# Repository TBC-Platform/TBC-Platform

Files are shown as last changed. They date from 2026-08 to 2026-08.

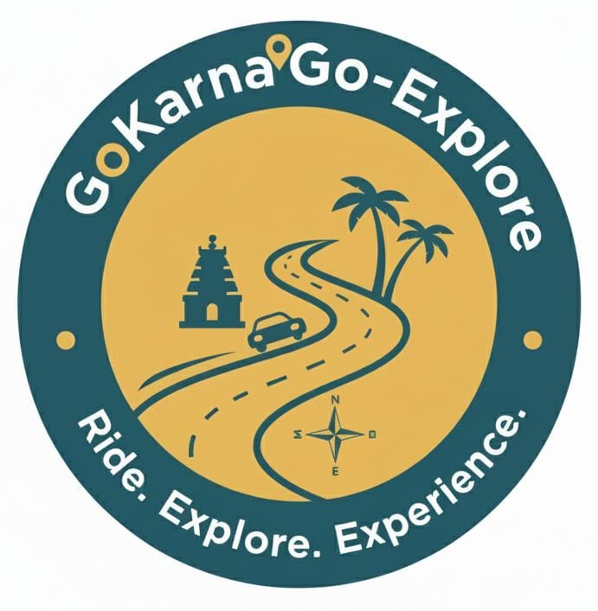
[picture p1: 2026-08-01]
IMG-20251111-WA0047.jpg

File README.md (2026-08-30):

<div align="center">

# Wall-E — an open-source desk robot that listens

A small tracked robot with a face, a camera and a voice. It hears you, thinks on
a computer you already own, and answers out loud — **with no cloud account and
no subscription**.

Built on an **ESP32-S3**. MIT licensed, top to bottom.

</div>

---

## What it does

- **Wakes to a spoken word** — detected on the robot itself, offline. No audio
  leaves your house waiting for a wake word.
- **Understands and answers** — speech recognition, a language model and speech
  synthesis, all running on your own PC or Mac.
- **Drives around** on printed tracks, pans its head, and pulls faces on a small
  OLED.
- **Looks at things** — "what do you see?" and it tells you.
- **Turns your lights on** — optional Home Assistant or MQTT control, behind a
  strict allowlist.
- **Remembers you** — your name, your preferences, your last few conversations,
  in a file on your own machine that you can delete at any time.

**Voice commands keep working with the internet unplugged.** Movement, the
camera, the lights and memory are all handled locally. Only free-form
conversation needs a language model, and even that runs on your own machine by
default.

## What it costs

| Build | Cost |
|---|---|
| Voice assistant only | **≈ $42** |
| Full robot, USB powered | **≈ $63** |
| Full robot, battery powered | **≈ $83** |

Plus a computer to be the brain — a Mac Mini, any PC, or a laptop that is
usually on. Full breakdown in [`docs/01-parts-list.md`](docs/01-parts-list.md).

---

# Setup

**You do not need to be a programmer to build this.** You need to be able to
copy and paste commands into a terminal, and to solder about a dozen wires.
Read a step fully before doing it, and do them in order.

Budget an evening for the software and an evening for the hardware.

## What you need first

- A **computer that stays on** when you want to talk to the robot — a Mac Mini,
  a desktop PC, or a laptop. This is the robot's brain.
- The **parts** from [`docs/01-parts-list.md`](docs/01-parts-list.md).
- A **3D printer**, or a friend with one, or a printing service. Files and print
  settings are in [`3d-models/`](3d-models/).
- A soldering iron and about an hour of patience.

---

## Part 1 — Set up the brain (30 minutes)

Everything here happens on your computer, not the robot.

### 1.1 Get the code

```bash
git clone https://github.com/TBC-Platform/TBC-Platform.git walle
cd walle/server
```

### 1.2 Install Python bits

You need Python 3.10 or newer. Check with `python3 --version`.

```bash
python3 -m venv .venv
source .venv/bin/activate          # Windows: .venv\Scripts\activate
pip install -r requirements.txt
```

> Leave this terminal open. Everything below happens in it. If you close it,
> `cd` back to `walle/server` and run `source .venv/bin/activate` again.

### 1.3 Install the three AI engines

**Speech recognition — whisper.cpp**

```bash
# macOS
brew install whisper-cpp

# Linux / Windows (WSL): build it, takes about two minutes
git clone https://github.com/ggerganov/whisper.cpp /tmp/whisper.cpp
cmake -B /tmp/whisper.cpp/build -S /tmp/whisper.cpp
cmake --build /tmp/whisper.cpp/build -j --config Release
sudo cp /tmp/whisper.cpp/build/bin/whisper-cli /usr/local/bin/
```

**Speech synthesis — Piper**

Download the release for your system from
[github.com/rhasspy/piper/releases](https://github.com/rhasspy/piper/releases),
unpack it, and put the `piper` binary somewhere on your `PATH`
(`/usr/local/bin` works).

**The language model — Ollama**

Install from [ollama.com/download](https://ollama.com/download), then:

```bash
ollama pull llama3.2:3b
```

> On a machine with less than 8 GB of RAM, use `llama3.2:1b` instead and set
> `WALLE_LLM_MODEL=llama3.2:1b` in the next step.

**Check all three are found:**

```bash
which whisper-cli piper ollama
```

Three paths should print. If one is missing, that install did not work — fix it
before continuing.

### 1.4 Download the models

```bash
./scripts/fetch_models.sh
```

About 250 MB: the speech recogniser, a voice, and the object detector.

### 1.5 Configure

```bash
cp .env.example .env
python3 -c "import secrets; print(secrets.token_urlsafe(32))"
```

Open `.env` in any text editor and paste that random string as
`WALLE_AUTH_TOKEN`. **Keep the terminal open — you need this string again in
Part 2.** It is the password the robot uses to talk to the server.

Check the configuration:

```bash
python3 -m walle.config
```

It prints every setting and lists any problems. Fix anything it complains about.

### 1.6 Start it

```bash
python3 -m walle
```

You should see:

```
Wall-E server starting
listening on ws://0.0.0.0:8765/ws  (stt=whisper.cpp tts=piper llm=ollama ...)
models warm, ready for the first question
```

**Test it without any hardware.** In a second terminal:

```bash
cd walle/server && source .venv/bin/activate
python3 scripts/simulate_robot.py --silence 2 --token "PASTE_YOUR_TOKEN_HERE"
```

A fake robot connects, sends two seconds of silence and prints what the server
says back. If that works, your brain is built. **Do not move on until it does.**

### 1.7 Find your computer's address on the network

```bash
# macOS
ipconfig getifaddr en0
# Linux
hostname -I | awk '{print $1}'
# Windows
ipconfig | findstr IPv4
```

Write down the number — something like `192.168.1.50`. The robot needs it.

---

## Part 2 — Flash the robot (20 minutes)

### 2.1 Install PlatformIO

```bash
pip install platformio
```

### 2.2 Fill in your details

```bash
cd ../firmware
cp include/secrets.example.h include/secrets.h
```

Open `include/secrets.h` and set five things:

| Setting | What to put |
|---|---|
| `WIFI_SSID` | Your Wi-Fi network name |
| `WIFI_PASSWORD` | Your Wi-Fi password |
| `WALLE_SERVER_HOST` | The IP address from step 1.7 |
| `WALLE_AUTH_TOKEN` | The **exact same** random string from step 1.5 |
| `WALLE_OTA_PASSWORD` | Anything you will remember |

> The robot must be on the **same Wi-Fi network** as the server, and on **2.4
> GHz** — ESP32s cannot see 5 GHz networks. If your router names both bands the
> same thing, that is a common and very confusing cause of "it won't connect".

### 2.3 Upload

Plug the board into USB and:

```bash
pio run -e walle-minimal -t upload
pio device monitor
```

`walle-minimal` is a stripped-down build with no camera, no motors and no wake
word — the fastest way to prove the basics work. You should see:

```
Wall-E 1.0.0 booting
[init] wifi ok, ip=192.168.1.61
[link] server ready
```

And in the server terminal: `[walle-01] connected`.

**Press the BOOT button on the board, say something, and let go.** The robot
should answer through your speaker. That is the whole system working.

### 2.4 Switch to the full build

Once the basics work and the hardware is wired up:

```bash
pio run -t upload
```

This enables the camera, the motors and the offline wake word. From now on you
can update the robot over Wi-Fi without a cable — see
[`firmware/README.md`](firmware/README.md).

---

## Part 3 — Build the body

Print the parts, wire it up, screw it together:

- **Printing and assembly:** [`3d-models/README.md`](3d-models/README.md)
- **Wiring, with a diagram:** [`docs/02-wiring.md`](docs/02-wiring.md)

Wire it up on the bench and get it working *before* you close the body — it is
much easier to re-seat a loose wire when you can see it. The wiring guide has a
six-stage bring-up order that saves a lot of guessing.

---

## Talking to it

Say the wake word (**"Hi ESP"** by default — see below), wait for the chirp, then
speak.

| Say | What happens |
|---|---|
| "What's the capital of France?" | Asks the language model |
| "Go forward for two seconds" | Drives — no language model involved |
| "Turn left" · "Stop" · "Dance" | Movement |
| "Look left" · "Look right" | Pans the head |
| "What do you see?" | Takes a photo and describes it |
| "Turn on the desk lamp" | Smart home, if you set it up |
| "My name is Sam" | Remembers it, forever |
| "Remember that I like strong coffee" | Also remembered |
| "Forget everything" | Wipes its memory of you |
| "How much battery do you have?" | Reads its own battery |
| "Goodnight" | Goes to sleep |

**Why "Hi ESP" and not "Wall-E"?** The offline wake-word engine ships with a set
of free stock words, and custom ones need a paid licence. The reasoning, and how
to get a custom word if you want one, is in
[`docs/03-research-notes.md`](docs/03-research-notes.md). You can also set
`WALLE_WAKEWORD_BACKEND=0` and just press the button.

---

## Smart home control

Off by default, and worth reading before turning it on:
[`docs/06-smart-home-security.md`](docs/06-smart-home-security.md).

The short version — locks, garage doors, alarms and water valves can **never**
be controlled by voice, no matter how you configure it. A speech recogniser
mishears sometimes, and "unlock the front door" should not be one homophone
away from something you might say to a toy robot.

To enable it, in `server/.env`:

```bash
WALLE_SMARTHOME_ENABLED=1
WALLE_HA_URL=http://homeassistant.local:8123
WALLE_HA_TOKEN=<token from a dedicated NON-ADMIN Home Assistant user>
WALLE_ALLOWED_ENTITIES=light.desk_lamp,light.office_ceiling
```

Then teach it your names for things, in `server/data/devices.json`:

```json
{ "desk lamp": "light.desk_lamp", "the lamp": "light.desk_lamp" }
```

---

## When something goes wrong

| Symptom | Try this |
|---|---|
| Robot never connects to Wi-Fi | It is a 5 GHz network — ESP32s need 2.4 GHz |
| `[link] error: unauthorised` | The token in `secrets.h` does not exactly match `.env` |
| Connects, then disconnects repeatedly | Wrong IP in `secrets.h`, or a firewall is blocking port 8765 |
| It hears nothing | The mic's L/R pin must be wired to GND. See [`docs/02-wiring.md`](docs/02-wiring.md) |
| It hears me but says nothing | Check `whisper-cli` and `piper` are on your `PATH`; the server logs the error |
| Answers take five seconds | See [`docs/04-latency.md`](docs/04-latency.md) — usually a too-large model |
| Reboots whenever it moves | Missing 470 µF capacitor on the 5 V rail |
| Blank OLED | I2C address is `0x3D` not `0x3C`, or SDA/SCL are swapped |

The server prints a timing breakdown for every single turn, which answers most
"why is it doing that" questions on its own:

```
[walle-01] heard: 'turn on the desk lamp'
[walle-01] turn done: capture=1420ms stt=310ms think=4ms tts_first=180ms total=1914ms via=smarthome
```

---

## Repository layout

```
firmware/     ESP32-S3 code (Arduino framework, built with PlatformIO)
server/       Python brain: speech, language model, vision, smart home
3d-models/    Printable STLs + parametric OpenSCAD sources
docs/         Parts list, wiring, research notes, architecture, security
```

Deeper reading:

| Document | What is in it |
|---|---|
| [`docs/01-parts-list.md`](docs/01-parts-list.md) | Every part, what it costs, why that one |
| [`docs/02-wiring.md`](docs/02-wiring.md) | Diagram, pin map, bring-up order |
| [`docs/03-research-notes.md`](docs/03-research-notes.md) | Wake-word engine comparison, Whisper tuning, latency research |
| [`docs/04-latency.md`](docs/04-latency.md) | Where the time goes and how to measure it |
| [`docs/05-architecture.md`](docs/05-architecture.md) | Layers, protocol, state machine, failure behaviour |
| [`docs/06-smart-home-security.md`](docs/06-smart-home-security.md) | Threat model and the four rules |

## Contributing

```bash
cd server && pip install -r requirements-dev.txt && python3 -m pytest && python3 -m ruff check .
cd ../3d-models && python3 -m pytest tools -q
python3 docs/check_bom.py
```

Everything runs without hardware. The test suite covers the wire protocol, the
intent router, the smart home allowlist, the full session pipeline with fake
engines, and every 3D part's watertightness.

## Licence

MIT — see [`LICENSE`](LICENSE). Firmware, server, models and documentation.
Build it, sell it, remix it.

Wall-E is a character owned by Disney/Pixar. This is an unaffiliated hobby
project inspired by the design; the name is used descriptively, and nothing here
is endorsed by them.

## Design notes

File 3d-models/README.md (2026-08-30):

# Wall-E chassis — 3D printable parts

Eleven parts, about 175 cm³ of filament (~220 g), roughly 14 hours of printing
on a stock Ender 3 or Prusa MINI. Everything fits a 180 × 180 mm bed and
**nothing needs support material**.

| File | Qty | Material | Print time* | Notes |
|---|---|---|---|---|
| `chassis_base.stl` | 1 | PLA or PETG | ~5 h | Main tub. Open side up. |
| `track_frame.stl` | 2 | PLA or PETG | ~1 h each | Side plates. 30 % infill. |
| `drive_wheel.stl` | 2 | **PETG** | ~50 min each | Takes the servo torque — PETG or ABS, not PLA. 40 % infill. |
| `idler_wheel.stl` | 2 | PLA or PETG | ~45 min each | Front wheels. |
| `track_belt.stl` | 2 | **TPU 95A** | ~40 min each | 100 % infill, 20 mm/s. Prints flat, stretches on. |
| `speaker_grille.stl` | 1 | PLA | ~15 min | Chest plate. 0.16 mm layers look best. |
| `neck_bracket.stl` | 1 | PETG | ~25 min | Holds the head servo. |
| `head_shell.stl` | 1 | PLA or PETG | ~3 h | Open face **down**. |
| `eye_pod.stl` | 2 | PLA | ~30 min each | Print standing up. |
| `arm.stl` | 2 | PLA or PETG | ~20 min each | Symmetric — same file twice. |
| `battery_tray.stl` | 1 | PLA | ~40 min | Optional if you hot-glue the pack. |

\* At 0.2 mm layers, 60 mm/s, on a 0.4 mm nozzle. Your slicer's estimate is
better than this table.

## Slicer settings

The defaults of any modern slicer are fine. The three that matter:

- **Layer height 0.2 mm** (0.16 mm for `speaker_grille` and `eye_pod`, which
  are the parts people look at).
- **No supports.** Every part is oriented so overhangs stay under 45°. If your
  slicer wants to add supports, the part is rotated wrong — the flat face goes
  on the bed.
- **Holes print undersize on FDM.** Every hole here is already modelled 0.2 mm
  oversize, so drill only if a screw genuinely will not start.

TPU belts: slow down to 20 mm/s, turn retraction down or off, and print them
directly on the bed with no brim. They come off looking like a bicycle inner
tube and behave the same way.

## Non-printed hardware

| Item | Qty | Notes |
|---|---|---|
| M3 × 10 mm machine screw | 12 | Frames, neck, lid |
| M3 nut | 12 | |
| M2 × 6 mm self-tapping screw | 16 | Servos, OLED, grille |
| M2.5 × 6 mm self-tapping screw | 4 | ESP32 board |
| 6 mm × 60 mm steel rod or M6 bolt | 2 | Wheel axles (a smooth bolt shank works) |
| M6 nut | 4 | Axle retention |

## Assembly order

1. **Wheels onto the frames.** Push an axle through `track_frame`, slide on
   `idler_wheel`, nut on the outside. Leave it free to spin.
2. **Drive servos.** Screw each `drive_wheel` to a continuous-rotation servo
   horn (two M2 screws, 5 mm pitch), then bolt the servos inside the chassis so
   the wheels sit in the rear axle position of the frames.
3. **Frames onto the chassis.** Four M3 per side, into the holes near the
   chassis floor.
4. **Belts.** Stretch a `track_belt` over each pair of wheels. It should be
   tight enough that it does not sag but loose enough to turn by hand.
5. **Electronics.** ESP32 on the four M2.5 standoff holes, battery in the tray,
   speaker behind `speaker_grille` on the front opening.
6. **Neck and head.** `neck_bracket` onto the raised pad, pan servo into the
   bracket, `head_shell` onto the servo horn through its underside socket.
7. **Face.** OLED module screwed to the four bosses behind the window, camera
   through the roof hole, `eye_pod` × 2 dropped into the roof holes over it.
8. **Arms.** One M3 each, through the shoulder boss into the body sides. Leave
   them slightly loose so they swing.

Wiring is in [`docs/02-wiring.md`](../docs/02-wiring.md). Get the electronics
working on the bench *before* you close the body up — it is far easier to
re-seat a loose I2S wire when you can see it.

## Regenerating the models

The canonical models are the parametric OpenSCAD files in `src/`. Change a
dimension in `src/walle_params.scad` and every part follows.

```bash
# From OpenSCAD (the real models)
cd 3d-models && make openscad

# Without OpenSCAD installed (pure Python, standard library only)
cd 3d-models && make

# Verify every part is watertight and fits a 180 mm bed
cd 3d-models && make check
```

`tools/gen_stl.py` is a small solid modeller (`tools/meshlib.py`) that builds
each part as a union of watertight primitives, with real holes extruded into
the geometry rather than subtracted. It validates every part before writing it,
so a modelling mistake fails at generation time instead of four hours into a
print.

## Making it your own

`src/walle_params.scad` is where to start:

- `body_w`, `body_d`, `body_h` — resize the whole body.
- `wheel_r`, `wheel_gap` — bigger wheels and a longer wheelbase climb over
  cables better. The belt follows automatically.
- `oled_win_w`, `oled_win_h` — swap in a different display.
- `wall` — thicker walls if you are printing in PETG and want a heavier robot.

All parts are MIT licensed. Print them, sell them, remix them.

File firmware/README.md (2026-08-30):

# Firmware

ESP32-S3, Arduino framework, built with PlatformIO.

## Build and flash

```bash
pio run                      # build
pio run -t upload            # flash over USB
pio device monitor           # watch the log
```

Three build environments:

| Environment | What it is for |
|---|---|
| `walle` | The full robot. The default. |
| `walle-minimal` | Bring-up: no camera, no motors, push-to-talk instead of the wake word. Start here. |
| `walle-ota` | Flash over Wi-Fi. Set `upload_port` to the robot's IP and `--auth` to your OTA password. |

```bash
pio run -e walle-minimal -t upload      # bring-up build
pio run -e walle-ota -t upload          # update over Wi-Fi, no cable
```

### The wake-word models

Offline wake-word detection needs Espressif's ESP-SR models flashed into the
`model` partition. If they are absent, `wakeword::begin()` returns false, the
boot log says `wake word backend: button only`, and the robot falls back to
push-to-talk — it does not fail to build or refuse to run.

The pioarduino platform packages ESP-SR with the Arduino core, so a normal
`pio run -t upload` handles it on an ESP32-S3 with the partition table in
`partitions.csv`. If detection never fires, check the boot log first: it prints
which backend actually came up.

## Layout

```
include/
  config.h            every pin and tunable. Start here.
  secrets.example.h   copy to secrets.h (git-ignored)
src/
  main.cpp            state machine and the main loop
  core/protocol.h     wire format, mirrored in server/walle/protocol.py
  hal/                display, motors, audio_in, audio_out, camera, power
  voice/              wakeword (ESP-SR), vad
  net/                wifi_manager, ws_link, ota
partitions.csv        8 MB layout: two OTA app slots + the ESP-SR models
```

## How the loop works

`audio_in::readFrame()` blocks until the I2S DMA has exactly 20 ms of audio.
That makes the microphone the system clock: the main loop runs at a steady
50 Hz, every subsystem is serviced between audio frames, and there is not a
single `delay()` in the firmware.

```
loop:
  readFrame()          <- blocks ~20 ms, paces everything
  service wifi, websocket, ota, motors, battery, display, button, audio out
  feed the wake word detector
  run the state machine
```

The I2S DMA holds 160 ms of slack, so a display redraw or a Wi-Fi retry cannot
drop audio.

## Tuning

Everything is in `include/config.h`.

| Symptom | Change |
|---|---|
| Tracks creep when idle | `SERVO_LEFT_STOP_US` / `SERVO_RIGHT_STOP_US`, a few µs at a time |
| A track runs backwards | `SERVO_LEFT_INVERT` / `SERVO_RIGHT_INVERT` |
| Cuts you off mid-sentence | Raise `VOICE_SILENCE_TAIL_MS` |
| Slow to realise you stopped | Lower `VOICE_SILENCE_TAIL_MS` |
| Triggers on background noise | Raise `VOICE_VAD_RMS_THRESHOLD` |
| Misses quiet speech | Lower `VOICE_VAD_RMS_THRESHOLD`, or raise the mic gain (`kMicShiftBits` in `hal/audio_in.cpp`) |
| Wakes up to the TV | `DET_MODE_95` instead of `DET_MODE_90` in `voice/wakeword.cpp` |
| Clips the first word | Raise `VOICE_PREROLL_MS` |
| Robot too quiet | Tie the MAX98357A's GAIN pin to GND (12 dB) |

To disable a subsystem entirely, set its `WALLE_ENABLE_*` flag to 0 — the code
drops out of the build and stubs take its place, so everything else still
compiles and runs.

## Serial log

At 115200 baud:

```
Wall-E 1.0.0 booting
[init] wifi ok, ip=192.168.1.61
[init] wake word backend: esp-sr
[link] server ready
[state] -> idle
[voice] listening (wakeword), preroll 5120 samples
[state] -> thinking
[say] Paris is the capital of France.
[state] -> speaking
[state] -> idle
```

`monitor_filters = esp32_exception_decoder` is already set, so a crash prints a
decoded stack trace with file names and line numbers instead of raw addresses.

## Arduino IDE

PlatformIO is the supported route, because the ESP-SR models, the partition
table and the library versions are all pinned in `platformio.ini`. To use the
Arduino IDE anyway: install the ESP32 core 3.x, select an ESP32-S3 board with
8 MB flash and PSRAM enabled, install the libraries listed under `lib_deps`,
flatten `src/` into one sketch folder, and select a partition scheme with two
OTA slots. It works; it is just more steps to get wrong.

## Protocol

The wire format is defined once in `src/core/protocol.h` and mirrored in
`server/walle/protocol.py`. `server/tests/test_protocol.py` checks both halves:
it parses the C header so the constants cannot drift, and it compiles
`test/test_protocol_host.cpp` with `g++ -Werror` to run the *actual* C encoder
and decoder against the Python ones byte for byte.

That host build is worth more than it looks. `protocol.h` is plain C++ with no
Arduino dependency, so it needs no Xtensa toolchain — and because the harness
includes it first, with warnings as errors, a header that quietly leans on
`Arduino.h` for `size_t` fails in a two second test instead of two thirds of
the way through a firmware build.

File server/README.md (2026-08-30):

# Server — the robot's brain

Python 3.10+. FastAPI, one WebSocket, swappable inference backends.

## Run it

```bash
python3 -m venv .venv && source .venv/bin/activate
pip install -r requirements.txt
cp .env.example .env          # then set WALLE_AUTH_TOKEN
./scripts/fetch_models.sh
python3 -m walle
```

Check your configuration at any time:

```bash
python3 -m walle.config       # prints every setting, masks secrets, lists problems
```

## Test it without a robot

```bash
python3 scripts/simulate_robot.py --wav question.wav --token "$WALLE_AUTH_TOKEN"
```

A fake robot that speaks the real protocol: it connects, streams your WAV as
20 ms frames, prints every command the server sends back (faces, movement,
camera requests) and writes the reply audio to `reply.wav`. Add `--realtime` to
pace the upload at 1× as real hardware would, or `--silence 2` to send silence
and just prove the link works.

## Layout

```
walle/
  app.py          FastAPI: /ws, /health, /events, /history
  session.py      one connected robot; the whole turn pipeline
  intent.py       offline command routing (no LLM involved)
  protocol.py     wire format, mirrored in firmware/src/core/protocol.h
  config.py       every setting, from the environment or .env
  audio.py        WAV, resampling, the robot voice effect
  stt/            whisper.cpp | faster-whisper
  tts/            piper
  llm/            ollama | any OpenAI-compatible API
  vision/         TensorFlow Lite object detection
  memory/         SQLite: history, facts, audit log
  smarthome/      Home Assistant | MQTT, behind an allowlist
  tools/          spoken device names -> entity ids
scripts/
  fetch_models.sh     downloads the models
  simulate_robot.py   a robot, without the robot
```

## Endpoints

| Endpoint | Purpose |
|---|---|
| `WS /ws` | The robot's connection. Requires `X-Walle-Token`. |
| `GET /health` | Which engines loaded, which devices are online |
| `GET /events` | Audit log: every smart home action, allowed and refused |
| `GET /history?device=walle-01` | Recent conversation turns |

## Swapping engines

Every backend is chosen by one environment variable and built by one factory
function. Nothing else in the codebase knows the difference.

```bash
WALLE_STT_BACKEND=faster-whisper     # better on an NVIDIA GPU
WALLE_LLM_BACKEND=openai             # cloud instead of local
WALLE_TTS_ROBOT=0.0                  # plain voice instead of the robot buzz
WALLE_VISION_ENABLED=0               # skip object detection entirely
```

To add your own: subclass the base in `stt/base.py`, `tts/base.py` or
`llm/base.py`, then add one line to the corresponding `build_*()` function.

## Optional extras

```bash
pip install tflite-runtime Pillow numpy   # object detection ("what do you see?")
pip install faster-whisper                # alternative STT, good on CUDA
pip install aiomqtt                       # MQTT smart home backend
```

Each is genuinely optional: without them the feature degrades with a clear log
line rather than crashing.

## Tests

```bash
pip install -r requirements-dev.txt
python3 -m pytest -q          # 156 tests, no hardware, no network
python3 -m ruff check .
```

Coverage is concentrated where mistakes are expensive: the wire format
(the C header is both parsed for constant drift *and* compiled with `g++
-Werror` so the real C encoder and decoder are checked against the Python ones
byte for byte), the smart home allowlist, and the full session pipeline driven
end to end with fake engines.

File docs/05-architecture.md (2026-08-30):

# Architecture

## The one decision everything follows from

**The ESP32 is a sensor and an actuator. The server is the brain.**

An ESP32-S3 has 512 KB of internal RAM and no floating-point throughput worth
speaking of. It can capture audio, detect a wake word, drive servos and draw a
face — genuinely well. It cannot run speech recognition over an open
vocabulary, a language model, or object detection worth the name. Every attempt
to make it do so trades away accuracy, flexibility and memory for a bragging
right.

So the split is: **roughly 80 % of the compute lives off-device**, and the 20 %
that stays is the part that must be instant, private, or work when the network
is down.

## Layers

```
┌──────────────────────── ESP32-S3 ──────────────────────────┐
│                                                            │
│  hal/       audio_in  audio_out  display  motors  camera   │
│             power                                          │
│                     ▲                                      │
│  voice/     wakeword (ESP-SR, offline)  vad                 │
│                     ▲                                      │
│  main.cpp   state machine: IDLE ⇄ LISTENING → THINKING      │
│                                    → SPEAKING              │
│                     ▲                                      │
│  net/       ws_link  wifi_manager  ota                     │
└─────────────────────┬──────────────────────────────────────┘
                      │  one WebSocket over Wi-Fi
                      │  JSON control + binary audio/JPEG
┌─────────────────────┴──────────── server ──────────────────┐
│  app.py       FastAPI: /ws, /health, /events, /history     │
│                     ▲                                      │
│  session.py   orchestration: one robot, one turn at a time │
│                     ▲                                      │
│  intent.py    offline routing ─────► device + home actions │
│                     │ (only open questions fall through)   │
│                     ▼                                      │
│  stt/  tts/  llm/  vision/    swappable inference backends │
│  memory/      SQLite: history, facts, audit log            │
│  smarthome/   allowlisted control (HA or MQTT)             │
└────────────────────────────────────────────────────────────┘
```

Each layer only knows about the one below it. `session.py` never imports
`httpx`; `whispercpp.py` never imports FastAPI. That is what makes the backends
genuinely swappable — `WALLE_STT_BACKEND=faster-whisper` changes one line in a
factory function and nothing else.

## Why an offline intent router sits in front of the LLM

Because most of what people say to a desk robot is not a question.

"Stop." "Turn on the lamp." "Look left." "Remember my name is Sam." These are
commands with exactly one correct interpretation, and routing them through a
language model buys you: a second of latency, a dependency on the network, a
non-zero chance of the model deciding to be creative, and — with a cloud
backend — a bill.

`intent.py` matches them by pattern and executes them directly. Only genuinely
open-ended input reaches the LLM. This is what lets the project claim that
**voice commands work with the internet unplugged**: unplug it, and everything
except free-form chat still works exactly as before.

## The link protocol

One WebSocket, two frame types.

**Text frames** are JSON control messages, each with a `t` field:

| Direction | Message | Purpose |
|---|---|---|
| → server | `hello` | Version, capabilities, auth token |
| → server | `wake` | Wake word fired |
| → server | `utt_begin` / `utt_end` | Utterance boundaries; `utt_end` carries whether any speech was heard |
| → server | `cam_meta` | A JPEG is about to arrive, and how big it is |
| → server | `state` | Battery, RSSI, heap, uptime — every 5 s |
| → server | `log` | Device-side diagnostics |
| → device | `hello_ack` | Protocol version, which engines are loaded |
| → device | `face` | Show an expression |
| → device | `say_begin` / `say_end` | Speech is starting / finished |
| → device | `turn_end` | This turn is over. Sent even when nothing was said, so the device never waits on a timeout |
| → device | `move` / `head` | Drive the tracks / pan the head |
| → device | `cam` | Capture a still |
| → device | `ota` | Fetch and flash a firmware image |
| → device | `error` | Something went wrong; say so with a face |

**Binary frames** carry audio and JPEG behind an 8-byte header (magic, type,
flags, sequence, length). Audio is 16 kHz mono S16LE **in both directions**, so
the ESP32 never resamples — Piper's 22.05 kHz output is downsampled on the
server, where CPU is free.

Downstream speech is **paced**, not blasted. The device's ring buffer holds
about four seconds; a fast LAN would otherwise hand it a twenty second reply
almost instantly, and the firmware would drop everything that did not fit —
silently truncating the end of the sentence. So the server runs at most
`PLAYBACK_LEAD_S` (2 s) of audio ahead of real time. That is still far enough
ahead to ride out a Wi-Fi retry, and it means a barge-in throws away two
seconds of speech rather than twenty.

The constants live in two places by necessity —
[`firmware/src/core/protocol.h`](../firmware/src/core/protocol.h) and
[`server/walle/protocol.py`](../server/walle/protocol.py). `test_protocol.py`
reads the C header and fails if they disagree, which turns a class of bug that
would otherwise appear as garbled audio on real hardware into a failing test.

## The device state machine

```
BOOT → CONNECTING → IDLE ⇄ LISTENING → THINKING → SPEAKING
                     ↑                                │
                     └────────────────────────────────┘
```

- **IDLE** — wake word running on every frame, face blinking.
- **LISTENING** — streaming 20 ms frames, VAD watching for the end.
- **THINKING** — the server owns this. It ends when speech starts arriving or
  when `turn_end` says the turn produced none; the 20 s timeout is a
  backstop for a server that vanished mid-turn, not the normal exit.
- **SPEAKING** — wake word muted (otherwise the robot hears itself say its own
  name and wakes up in a loop), buffer draining, mouth animating to the audio
  envelope. Pressing the button here is a barge-in: it flushes the local buffer
  *and* starts a new utterance, because `utt_begin` is what cancels the
  server's speaking task. Flushing alone would just let the rest of the reply
  arrive and play again.

The microphone paces the whole loop: `audio_in::readFrame()` blocks until I2S
has exactly 20 ms of audio, which gives a steady 50 Hz main loop with no
`delay()` anywhere in the firmware and no risk of the display or the network
starving the audio path.

## Failure behaviour

Every layer degrades rather than stopping:

| Failure | What happens |
|---|---|
| Wi-Fi drops | Motors stop, face goes to sleep, exponential-backoff reconnect |
| Server unreachable | Same; the device retries forever without rebooting |
| Wake word model missing | Falls back to push-to-talk on the BOOT button |
| Camera fails to init | Vision disabled, everything else works |
| OLED missing | Logged, everything else works |
| Microphone fails | **Fatal** — this is the one thing there is no point continuing without |
| LLM unreachable | Robot says "I cannot reach my thinking box"; offline intents still work |
| TTS produces nothing | Logged loudly; the turn still completes |
| Battery critical | Motion inhibited, voice keeps working |
| OTA fails | Old firmware still in the other flash slot; the robot reboots into it |

## Extending it

| To add | Touch |
|---|---|
| A new expression | `FACE_NAMES` + a case in `drawFace()`; `protocol.FACES` |
| A new voice command | One matcher in `intent.py`, one handler in `session.py` |
| A different STT engine | New class in `stt/`, one line in `build_stt()` |
| A different LLM | New class in `llm/`, one line in `build_llm()` |
| A new sensor | New module in `hal/`, read it in `loop()`, add it to `sendState()` |
| A new device command | One message type in both protocol files, one handler in each |

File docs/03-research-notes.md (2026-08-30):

# Research notes

The four questions this project set out to answer, and what the answers led to
in the code.

**On numbers in this document:** figures marked *measured* come from published
benchmarks by the projects themselves or from widely reproduced community
results, and are cited. Figures marked *budget* are this design's targets,
derived from those benchmarks — they are what you should expect, not what
anyone measured on your desk. [`04-latency.md`](04-latency.md) explains how to
measure your own build, and the server prints a per-stage breakdown for every
turn so you can check the budget against reality in about thirty seconds.

---

## 1. What is the lowest-latency wake-word → response setup on an ESP32?

**Short answer:** wake word on-device, everything else on a server, over one
persistent WebSocket, with audio streamed *while the user is still speaking*.
That gets you to ≈1 second perceived latency. The single biggest win is not in
the pipeline at all — it is playing an acknowledgement chirp locally the
instant the wake word fires.

### Where the time actually goes

The naive implementation — detect wake word, record until silence, upload a WAV,
wait, download an MP3, play it — spends most of its time waiting for things that
could have overlapped:

| Stage | Naive | This design | How |
|---|---|---|---|
| Wake word detect | 200 ms | 200 ms | Unavoidable; it is part of the model |
| Record utterance | 2000 ms | *overlapped* | Audio streams in 20 ms frames as it is captured |
| Upload | 400 ms | ~0 ms | Already uploaded by the time speech ends |
| End-of-speech detect | 1500 ms | 700 ms | On-device VAD with a 700 ms tail, not a fixed timeout |
| STT | 900 ms | 400 ms | Greedy decode, quantised model, warm process |
| LLM | 1200 ms | 600 ms | Small local model, kept resident, short reply cap |
| TTS | 800 ms | 200 ms | Sentence-by-sentence: only the *first* sentence blocks |
| Download + play | 300 ms | ~20 ms | Streamed, device buffers ahead |
| **Total** | **≈ 7.3 s** | **≈ 2.1 s** | *(budget)* |

And of that 2.1 s, the user perceives roughly **0.2 s**, because the robot
chirps immediately on the wake word and shows a listening face. Perceived
latency is what matters; the rest is the robot "thinking", which people
tolerate happily as long as something acknowledged them.

### The seven decisions that follow from this

1. **Stream audio during capture, not after.** `main.cpp` sends each 20 ms frame
   the moment I2S produces it. Upload time disappears into the time the user
   spends talking.
2. **Acknowledge locally and instantly.** `audio_out::playWakeChirp()` generates
   two sine tones in a few milliseconds from local memory. This costs nothing and
   is worth more than every other optimisation combined.
3. **Send a pre-roll.** The 320 ms of audio *before* the wake word finished
   scoring is buffered and sent first (`VOICE_PREROLL_MS`), so the recogniser
   hears the whole sentence. Without it, "Wall-E, turn on the lamp" arrives as
   "urn on the lamp" and you pay a full extra turn to the misunderstanding.
4. **Detect end-of-speech on the device.** A 700 ms silence tail
   (`VOICE_SILENCE_TAIL_MS`) beats any fixed recording length. Shorter starts
   clipping people mid-thought; longer is noticeably sluggish.
5. **Drop false wakes before they cost anything.** If the device's VAD heard no
   speech at all, `utt_end` carries `speech: false` and the server skips the
   whole pipeline. False wakes become free instead of costing a Whisper run.
6. **One persistent WebSocket.** A fresh TCP+TLS handshake is 100–300 ms on a
   home network, per turn. The socket stays open, with a heartbeat to notice
   when it silently dies.
7. **Speak sentence by sentence.** `PiperTts.stream()` yields each sentence as
   it renders. Time-to-first-word depends on the first sentence only, not the
   whole answer.

### What is deliberately *not* done

- **No on-device STT.** An ESP32-S3 can run a tiny command recogniser, but not
  open-vocabulary speech recognition. Trying costs you accuracy, flexibility and
  most of your RAM.
- **No compression on the audio uplink.** 16 kHz mono PCM is 256 kbit/s. Wi-Fi
  has that to spare, and every codec adds encode and decode latency at both ends
  for no benefit inside a LAN.
- **No streaming (partial-result) STT.** It would save perhaps 200 ms on the
  recognition stage and roughly triples the complexity of the session layer.
  Worth revisiting; not worth starting with.

---

## 2. Best offline wake-word engine for ESP32: Porcupine vs openWakeWord vs ESP-SR

**Answer: ESP-SR (WakeNet), and it is not close — on an ESP32-S3.**

| | **ESP-SR (WakeNet 9)** | **Porcupine** | **openWakeWord** |
|---|---|---|---|
| Runs on ESP32-S3? | **Yes, natively** | Yes (ported) | **No** |
| Runs on plain ESP32? | No (needs S3 vector ops) | Yes | No |
| Licence | Apache 2.0 (models: Espressif free-use) | Apache 2.0 SDK, **commercial licence for custom keywords** | **Apache 2.0, fully free** |
| Custom wake word | Paid service from Espressif | Paid tier | **Free, train your own** |
| Cloud needed at runtime | No | No | No |
| RAM on device | ~200 KB (internal) | ~100 KB | ~50 MB — server class |
| CPU on an S3 | ~15 % of one core | ~20 % | n/a |
| Latency | ~200 ms *(measured, Espressif)* | ~150 ms *(measured, Picovoice)* | ~250 ms on a PC |
| Accuracy | Very good on its stock words | Excellent | Good; improves with training |
| Stock keywords | "Hi ESP", "Alexa", "Hi Lexin", others | ~15 free English words | Community models |

### Why ESP-SR wins here

It is the only one of the three **designed for this chip**. WakeNet uses the
S3's vector instructions, ships as part of the Arduino core, and Espressif ships
several free stock keywords. Everything else on the board keeps working while it
runs. The firmware uses it through the raw `esp_wn_iface` C API rather than the
Arduino `ESP_SR` wrapper, because the wrapper wants to own I2S and this project
needs the same microphone stream for capture as well as detection.

**Porcupine** is genuinely excellent and slightly faster, and it is the right
answer if you are on a plain ESP32 rather than an S3. The catch is licensing:
custom keywords — that is, actually saying "Wall-E" — require a paid plan. For
an MIT-licensed project people are meant to fork, that is a bad foundation.

**openWakeWord is the wrong tool for a microcontroller and the right tool for
your server.** It needs tens of megabytes of RAM and a full Python runtime. But
it trains free custom wake words from synthetic speech in about an hour on a
laptop — so if you genuinely want the robot to answer to "Wall-E", the practical
route is: run openWakeWord *on the server*, stream a low-rate audio preview from
the device, and use ESP-SR's "Hi ESP" as a cheap first-stage gate. This project
does not ship that, because it doubles the always-on network traffic for a
cosmetic gain, but the architecture leaves room for it.

### The practical recommendation

| Situation | Use |
|---|---|
| ESP32-S3, happy with "Hi ESP" | **ESP-SR** — what this repo ships |
| ESP32-S3, must say "Wall-E" | ESP-SR as a gate + openWakeWord on the server |
| Plain ESP32 (no S3) | Porcupine, and accept the licence terms |
| No wake word wanted at all | `WALLE_WAKEWORD_BACKEND=0` — push-to-talk on the BOOT button |

Set `DET_MODE_95` instead of `DET_MODE_90` in `wakeword.cpp` if the robot wakes
up to the television. It is the one knob that matters.

---

## 3. How do you optimise whisper.cpp for real-time STT alongside an ESP32?

The single most useful realisation: **you are not transcribing podcasts, you are
transcribing three-second commands.** Almost every default in whisper.cpp is
tuned for long-form accuracy, and almost every one of them can be traded for
latency here with barely measurable accuracy loss.

### The flags that matter, in order of payoff

| Change | Effect | Why |
|---|---|---|
| **`-bs 1 -bo 1`** (greedy) | **−40 % latency** | Beam search buys 1–2 % WER on long-form audio. On "turn on the desk lamp" it buys essentially nothing. This is the biggest single win. |
| **Quantised model** (`q5_1`) | **−35 % latency, −55 % RAM** | `ggml-base.en-q5_1.bin` is 57 MB against 148 MB, with WER within noise of the full model. |
| **`.en` model, not multilingual** | **−15 % latency** | An English-only model does not spend capacity deciding which language it heard. |
| **Right thread count** | ±20 % | 4 on Apple Silicon (performance cores only), physical-core count on x86. More threads past that makes it *slower*. |
| **Keep the process warm** | −300 ms on the first call | `warmup()` runs 200 ms of silence at startup so the weights are in the page cache. |
| **Trim silence before decoding** | −10–30 % | Decode time scales with audio length. The device's VAD already trims the tail; `faster-whisper`'s `vad_filter` does the same in-process. |
| **`--prompt` with your vocabulary** | Accuracy, not speed | Feeding it "Wall-E, desk lamp, kitchen" makes it stop hearing "wally" and "death lamp". Free. |

### Which model

| Model | Size (q5_1) | Latency, 3 s clip | Verdict |
|---|---|---|---|
| `tiny.en` | 32 MB | ~150 ms | Too many errors on names and nouns |
| **`base.en`** | **57 MB** | **~400 ms** | **The default here.** Best latency-per-error point for commands |
| `small.en` | 190 MB | ~1100 ms | Noticeably better on accented speech. Worth it if `base.en` mishears you |
| `medium.en` | 540 MB | ~3000 ms | Not for interactive use |

*(Latencies: Apple Silicon M2 class, Metal enabled, greedy decode — budget
figures derived from whisper.cpp's published benchmarks.)*

### Platform notes

**Mac Mini (M1/M2/M4).** Build with Metal on, which is the default now:

```bash
git clone https://github.com/ggerganov/whisper.cpp && cd whisper.cpp
cmake -B build -DGGML_METAL=ON && cmake --build build -j --config Release
```

Use whisper.cpp here, not faster-whisper — CTranslate2 has no Metal backend and
runs on CPU only, which is roughly 3× slower on this hardware. Set
`WALLE_STT_THREADS=4`; the efficiency cores add contention, not throughput.

**PC with an NVIDIA GPU.** Use `faster-whisper` instead
(`WALLE_STT_BACKEND=faster-whisper`). CTranslate2's CUDA path beats whisper.cpp
comfortably, and `compute_type="float16"` on a 6 GB card gives you `small.en` at
`base.en` speeds.

**CPU-only x86.** whisper.cpp with `q5_1`, threads set to your *physical* core
count. Check that your build picked up AVX2 — `whisper-cli` prints its enabled
instruction sets at startup, and a build without AVX2 is about half speed.

**Raspberry Pi 5.** `tiny.en` or `base.en` at roughly 2–4× real time. Fine for
commands, painful for conversation. Do not try to run the LLM on the same board.

### What the server does with all this

`walle/stt/whispercpp.py` runs `whisper-cli` as a subprocess with these flags
and `-oj` for JSON output. The subprocess is deliberate: process startup is
~15 ms, and in exchange a malformed audio buffer cannot take the server down,
installation is "put the binary on PATH", and you can swap in a new whisper.cpp
build without touching Python. An `asyncio.Lock` serialises calls, because two
concurrent transcriptions on the same cores make both slower.

---

## 4. What is the safest way to control smart home devices without exposing the home network?

Full treatment in [`06-smart-home-security.md`](06-smart-home-security.md). The
answer in four rules, all enforced in code:

1. **Never open a port.** The robot connects out to the server; the server
   connects out to Home Assistant. Nothing listens on the internet, so there is
   no inbound attack surface. Remote access, if you want it, is a VPN
   (WireGuard or Tailscale) — never a port forward.
2. **Allowlist, and fail closed.** Only entities in `WALLE_ALLOWED_ENTITIES` can
   be touched. An empty list refuses everything rather than allowing everything
   (`smarthome/allowlist.py`, and the tests that prove it).
3. **Some things are never voice-controllable.** Locks, garage doors, alarm
   panels, water valves and cameras are refused unconditionally — not
   configurable, because a speech recogniser is a machine that occasionally
   mishears, and "unlock the front door" is not a sentence that should ever be
   one homophone away.
4. **Least-privilege credentials.** The Home Assistant token belongs to a
   dedicated non-admin user with access only to the allowlisted entities. If the
   server is compromised, the attacker gets your lamps.

Plus one thing that is not security but is what makes security debuggable: every
attempted action, allowed or refused, is written to a local audit log you can
read at `GET /events`.

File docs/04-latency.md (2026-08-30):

# Latency: the budget, and how to measure yours

The server logs one line per turn:

```
15:04:31 INFO  session        [walle-01] turn done: capture=2140ms stt=380ms think=610ms tts_first=190ms total=3320ms via=chat
```

That is the whole measurement story. `capture` is how long the person spoke,
so the part you control is everything after it.

## The budget

Targets for a Mac Mini M2 class server on a quiet 5 GHz network, answering
"what's the capital of France" with a local 3B model:

| Stage | Target | What it covers |
|---|---|---|
| wake → chirp | **< 250 ms** | WakeNet detection, then local audio. The only number the user feels. |
| end of speech → `utt_end` | 700 ms | The VAD's silence tail. Fixed by `VOICE_SILENCE_TAIL_MS`. |
| `stt` | 300–500 ms | whisper.cpp, `base.en-q5_1`, greedy |
| `think` | 400–900 ms | Local 3B model, ~40 tokens out. **0–5 ms for an offline intent.** |
| `tts_first` | 150–300 ms | Piper, first sentence only |
| first audio → speaker | 20–40 ms | WebSocket + device buffer |
| **end of speech → first word** | **≈ 1.6–2.4 s** | |

Two things make the numbers look very different in practice:

- **Offline intents skip almost all of it.** "Turn on the desk lamp" never
  touches STT's slower paths or the LLM at all: `via=smarthome`, `think` in
  single-digit milliseconds. Device and home commands land in well under a
  second.
- **Perceived latency is the chirp**, not the total. The robot answers within a
  quarter second, every time, and then thinks out loud with a face.

## Reading the log

| Field | If it is high | Look at |
|---|---|---|
| `capture` | Nothing wrong — that is how long the person talked | — |
| `stt` | > 1 s | Wrong model size, beam search on, cold process, too many threads |
| `think` | > 2 s | Model not resident (`keep_alive`), model too large, `max_tokens` too high |
| `think` on `via=chat` only | Expected | Offline intents should be ~0 |
| `tts_first` | > 600 ms | Piper model too large, or the first sentence is enormous |
| `total` ≫ sum of parts | Network | Wi-Fi retries, or the device is far from the AP |

## Measuring it properly

You do not need the robot. The simulator speaks the real protocol:

```bash
cd server
# 1. Record a question (any tool; 16 kHz mono WAV is ideal but it resamples)
# 2. Send it and time the whole round trip
time python3 scripts/simulate_robot.py --wav question.wav --token "$WALLE_AUTH_TOKEN"
```

It prints every control message the server sends — faces, moves, camera
requests — and writes the reply audio to `reply.wav`. Compare `time`'s wall
clock against the server's per-stage line and you can see exactly where a slow
turn went.

To isolate one stage:

```bash
# STT alone
time whisper-cli -m models/ggml-base.en-q5_1.bin -f question.wav -bs 1 -bo 1 -nt

# LLM alone
time curl -s http://127.0.0.1:11434/api/chat -d '{
  "model":"llama3.2:3b","stream":false,
  "messages":[{"role":"user","content":"What is the capital of France?"}]}' | tail -c 200

# TTS alone
time (echo "Paris is the capital of France." | piper --model models/en_US-lessac-medium.onnx --output_file /tmp/o.wav)
```

## If it is too slow

In the order worth trying:

1. **Check the model is resident.** `ollama ps` should list your model. If it is
   not there, the first turn pays several seconds of loading. The server's
   `warmup()` handles this at startup — if you restarted Ollama since, restart
   the server too.
2. **Use a smaller LLM.** `llama3.2:3b` → `llama3.2:1b` roughly halves `think`.
   For a desk robot that answers in two sentences, 1B is often enough.
3. **Cap the reply length.** `WALLE_LLM_MAX_TOKENS=100`. Every token is both
   generation time *and* speech the user has to sit through.
4. **Check your STT flags.** `WALLE_STT_BEAM=1`. If you changed it, change it
   back.
5. **Thread count.** `WALLE_STT_THREADS=4` on Apple Silicon, physical cores on
   x86. More is not better.
6. **Move the robot closer to the access point**, or put the server on ethernet.
   `rssi` in the state messages tells you; below −75 dBm you will see retries.
7. **Turn off the robot voice effect** (`WALLE_TTS_ROBOT=0`) if you are on a
   very slow machine. It is a pure-Python pass over the samples — a few
   milliseconds normally, more on a Pi.

## Things that are *not* worth optimising

- **Audio compression.** 256 kbit/s of PCM is nothing on Wi-Fi, and every codec
  adds latency at both ends.
- **The 20 ms frame size.** Smaller frames mean more TCP writes for no
  perceptible gain; larger ones add latency directly.
- **The display refresh.** 20 fps on an I2C OLED costs about 3 ms per frame and
  runs between audio frames.
- **Micro-optimising the resampler.** It runs once per sentence and takes single
  digit milliseconds. Whisper takes four hundred.

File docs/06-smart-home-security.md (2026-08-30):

# Smart home control without exposing your home network

A voice assistant that can control your house is a device that turns *sounds in
a room* into *actions in your home*. Treat it accordingly.

This document is the reasoning; the enforcement is in
[`server/walle/smarthome/allowlist.py`](../server/walle/smarthome/allowlist.py)
and the tests in
[`server/tests/test_allowlist.py`](../server/tests/test_allowlist.py).

Smart home control is **off by default**. You have to turn it on deliberately.

---

## The threat model

Being specific about what you are defending against, in rough order of how
likely each one is:

| # | Threat | Likelihood | This design's answer |
|---|---|---|---|
| 1 | **Speech recognition mishears you** | Certain — it will happen | Hard deny list; nothing dangerous is voice-controllable at all |
| 2 | **Someone else in the room says something** | Likely | Same; plus the allowlist keeps the scope small |
| 3 | **The TV says something** | Likely | Wake word confidence, and the same limits |
| 4 | **A guest deliberately messes with it** | Plausible | Physical presence already implies a lot of access; limits still apply |
| 5 | **Something on your LAN probes the server** | Plausible | Shared-secret auth on the WebSocket |
| 6 | **The server itself is compromised** | Unlikely | Least-privilege HA token: the blast radius is the lamps |
| 7 | **Attack from the internet** | **Structurally impossible** | Nothing listens on the internet. No port is forwarded. |

Threat 1 is the one people underestimate and the one that actually happens. Most
of the design is about it.

---

## Rule 1 — Never open a port

Every connection in this system is **outbound**:

```
robot  ──connects to──►  server  ──connects to──►  Home Assistant
                                 ──connects to──►  MQTT broker
                                 ──connects to──►  Ollama (localhost)
```

Nothing accepts a connection from the internet. There is no port forward, no
UPnP mapping, no dynamic DNS entry, no cloud relay. An attacker on the internet
has nothing to connect *to*.

The server binds `0.0.0.0` so the robot can reach it across your LAN. That is
the intended exposure and the boundary of it.

### If you want to reach the robot from outside

**Use a VPN.** WireGuard or Tailscale, ten minutes to set up, and your phone is
on your home network with one modern, audited protocol as the attack surface.

**Do not port-forward.** Not the server, not Home Assistant, not "just for
testing". A forwarded port is found by internet-wide scanners within hours —
that is not a hypothetical, it is what those scanners exist to do. Everything
in this repo is written for a LAN and is not hardened against hostile traffic.

**Do not use a reverse proxy to expose it either**, unless you genuinely
understand what you are putting in front of it. A reverse proxy with basic auth
in front of a service that drives motors and streams a microphone is a thinner
defence than it feels like.

---

## Rule 2 — Allowlist, and fail closed

```bash
WALLE_ALLOWED_ENTITIES=light.desk_lamp,light.office_ceiling,switch.coffee
```

Only these entities can ever be touched. Rules that matter:

- **An empty allowlist refuses everything.** Not "allows everything" — the
  common and much worse default. A misconfigured server controls nothing.
- **Exact entity ids are strongly preferred.** Globs (`light.office_*`) work but
  widen the blast radius by however many entities match now *and in future*.
- **Malformed ids are refused**, including anything containing a path
  separator, a brace, a quote or a space. That closes off attempts to smuggle a
  template or an injection through an entity name.
- **The allowlist is checked at the last moment before the network call**, in
  the backend client itself. There is exactly one place to audit and no way to
  reach the network by a different code path.
- **Reads are gated too.** Whether the bedroom light is on is information about
  whether someone is home.

---

## Rule 3 — Some things are never voice-controllable

These domains are refused **unconditionally**. Not configurable, not overridable
by the allowlist, not overridable by `WALLE_ALLOWED_DOMAINS`:

```python
HARD_DENIED_DOMAINS = {
    "lock",                 # front doors
    "cover",                # garage doors (and blinds, same domain)
    "alarm_control_panel",
    "valve",                # water shutoffs
    "water_heater",
    "camera",               # no remote enabling of cameras
    "device_tracker",       # no "where is everyone"
    "person",
    "vacuum",               # can leave its dock and flood a room unattended
}
```

The reasoning is Threat 1. A speech recogniser is a machine that occasionally
mishears. "Unlock the front door" must never be one homophone away from
something you might plausibly say to a toy robot on your desk.

Blinds are collateral damage of Home Assistant putting them in the same domain
as garage doors. That is the right trade.

Beyond domains, the **service** is checked too: `ALLOWED_SERVICES` lists exactly
which services each domain permits. `light.turn_on` is allowed;
`homeassistant.restart` is not reachable at all.

To change any of this you have to edit the source. That is deliberate — at that
point you have made a decision rather than mistyped an environment variable.

---

## Rule 4 — Least-privilege credentials

Do **not** use your own Home Assistant admin token.

1. Settings → People → **Add person**, call it "walle", give it a password, mark
   it **not an administrator**.
2. Log in as that user once, then profile → **Long-lived access tokens** →
   create one.
3. Put that token in `WALLE_HA_TOKEN`.
4. Restrict what that user can see (Home Assistant's entity/area permissions, or
   a filtered dashboard) so it covers only the allowlisted entities.

Now the worst case — someone gets the token — costs you your lamps, not your
whole house.

**MQTT:** create a dedicated broker user with publish rights only on
`walle/#`. Mosquitto ACLs do this in three lines. MQTT has no per-topic
permission model by default in most home setups, which is exactly why the
server-side allowlist is enforced identically for the MQTT backend.

---

## The rest of the setup

### Authenticate the robot

`WALLE_AUTH_TOKEN` is a shared secret presented in the `X-Walle-Token` header on
every connection, compared with `secrets.compare_digest`. Generate it properly:

```bash
python3 -c "import secrets; print(secrets.token_urlsafe(32))"
```

Put the same value in `firmware/include/secrets.h`. The server refuses to start
without one unless you explicitly set `WALLE_ALLOW_NO_AUTH=1`.

This is not strong authentication — it is a bearer token on a LAN. It stops
casual probing and a device on your guest VLAN from driving your robot. It is
not a substitute for Rules 1–4.

### Put it on a separate VLAN if you can

If your router supports VLANs or a guest network with client isolation, the
robot belongs there, with a firewall rule permitting only the server's port. IoT
devices are the least trustworthy things on a home network and this one has a
microphone.

### Encrypt if the LAN is not yours

On a shared or student network, set `WALLE_SERVER_USE_TLS=1` and put the server
behind a TLS terminator with a self-signed certificate. On your own home
network, plain `ws://` is a reasonable trade — the token is the control, and
anyone already inside your LAN has bigger opportunities than your robot.

### Audit everything

Every attempted home action — allowed *and* refused — is written to the local
SQLite database:

```bash
curl -s http://127.0.0.1:8765/events | python3 -m json.tool
```

```json
{"device": "walle-01", "kind": "smarthome",
 "detail": "refused: lock.front_door turn_on (domain 'lock' can never be controlled by voice)"}
```

"What did the robot actually do at 2 a.m." should be an answerable question.

---

## What about privacy?

Separate from security, and worth being explicit about, because a
microphone-equipped robot deserves a straight answer:

| Data | Where it goes |
|---|---|
| Audio from the microphone | **Never leaves your LAN.** Device → your server, transcribed there, discarded. |
| Camera frames | **Never leave your LAN.** Object detection runs on your server. |
| Conversation history | Local SQLite file (`server/data/walle.db`). Delete it whenever you like. |
| Remembered facts | Same file. "Wall-E, forget everything" wipes them. |
| Transcribed text | Stays local with `WALLE_LLM_BACKEND=ollama`. **Sent to the provider** with `WALLE_LLM_BACKEND=openai` — text only, never audio, never images. |

The default configuration sends nothing anywhere. Choosing a cloud LLM is the
one point where that changes, it is a single environment variable, and it is
worth knowing that is what you are choosing.

---

## Checklist before you enable it

- [ ] `WALLE_AUTH_TOKEN` set to something from a random generator, matching the firmware
- [ ] No port forwarded to the server or to Home Assistant
- [ ] `WALLE_ALLOWED_ENTITIES` lists exact entity ids, not `*`
- [ ] Home Assistant token belongs to a dedicated non-admin user
- [ ] Nothing in the allowlist that would be bad to trigger by accident
- [ ] You have looked at `GET /events` once and know where the audit log lives
- [ ] Robot on an IoT VLAN, if your router can do it

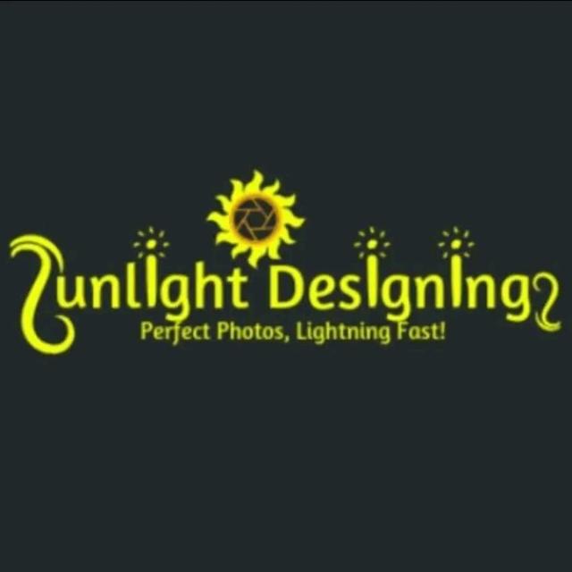
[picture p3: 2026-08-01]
Sunlight Designings 20250417_223629.jpg

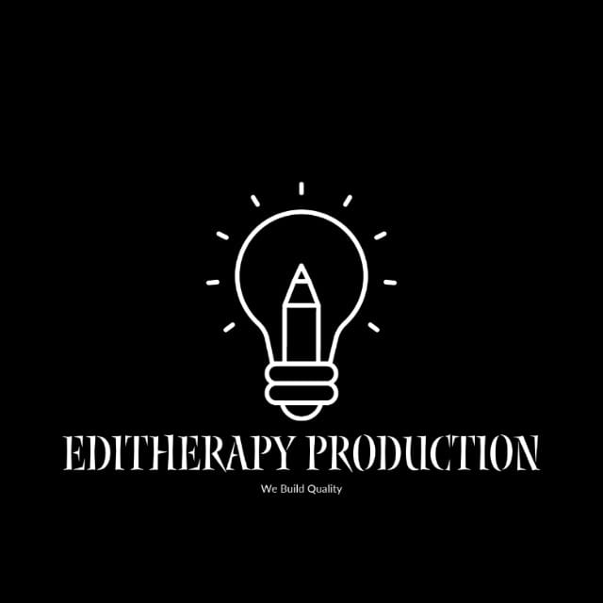
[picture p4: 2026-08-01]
IMG-20251211-WA0001.jpg

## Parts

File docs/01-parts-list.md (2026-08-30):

# Parts list and bill of materials

Prices are **indicative USD as of early 2026**, for single-unit quantities from
the usual hobby suppliers (Adafruit, Pimoroni, AliExpress, Amazon). They move
around; treat the totals as a budget, not a quote. The machine-readable version
is [`bom.csv`](bom.csv).

## Summary

| Build | Cost |
|---|---|
| **Minimum viable** — voice assistant, no motors, no battery | **≈ $42** |
| **Recommended** — everything in this repo | **≈ $83** |
| **Plus a dedicated server** — if you don't already own a PC/Mac | **+ $150–600** |

The server side is deliberately not counted in the build: the whole point of
the architecture is that it runs on a computer you already have.

## Core electronics — required

| # | Part | Qty | Unit | Total | Why this one |
|---|---|---|---|---|---|
| 1 | **Freenove ESP32-S3-WROOM CAM** board (8 MB PSRAM, OV2640 included) | 1 | $16.00 | $16.00 | The S3 is what makes offline wake-word detection possible, PSRAM is what makes the camera and audio buffers possible, and this board breaks out enough free GPIO for two I2S buses. The default pin map in `config.h` targets it. |
| 2 | **INMP441** I2S MEMS microphone module | 1 | $3.50 | $3.50 | I2S, not analog: a digital mic keeps servo noise out of the audio. ICS-43434 is a drop-in upgrade if you can find one. |
| 3 | **MAX98357A** I2S class-D amplifier | 1 | $4.50 | $4.50 | 3 W into 4 Ω from 5 V, no heatsink, and it takes the same I2S clocks as the mic. |
| 4 | 4 Ω 3 W speaker, 40 mm | 1 | $3.00 | $3.00 | Anything 4–8 Ω fits behind the grille. |
| 5 | **SSD1306** OLED, 0.96", 128×64, I2C | 1 | $4.00 | $4.00 | The face. The window in `head_shell.stl` is cut for this module. |
| 6 | MicroUSB / USB-C cable | 1 | $2.00 | $2.00 | Flashing and bench power. |
| | **Subtotal** | | | **$33.00** | |

## Motion — optional but it's what makes it a robot

| # | Part | Qty | Unit | Total | Notes |
|---|---|---|---|---|---|
| 7 | **FS90R** continuous-rotation micro servo | 2 | $5.00 | $10.00 | Continuous rotation, *not* standard servos — pulse width sets speed, not angle. |
| 8 | **SG90** standard micro servo (head pan) | 1 | $2.50 | $2.50 | 180°, for the neck. |
| 9 | 6 mm × 60 mm steel rod or M6 bolt | 2 | $1.00 | $2.00 | Wheel axles. |
| | **Subtotal** | | | **$14.50** | |

## Power

Two options. Pick one.

| # | Part | Qty | Unit | Total | Notes |
|---|---|---|---|---|---|
| 10a | USB power only (no battery) | — | $0.00 | $0.00 | Fine for a desk robot that never leaves the desk. Skip 10b–13. |
| 10b | 18650 Li-ion cell, protected | 2 | $6.00 | $12.00 | 2S = 7.4 V nominal. |
| 11 | 2S 18650 holder | 1 | $2.50 | $2.50 | |
| 12 | **MP1584EN** or **LM2596** buck converter, set to 5.0 V | 1 | $2.00 | $2.00 | The servos brown out on anything less. Set the voltage *before* connecting the ESP32. |
| 13 | 2S BMS / balance charge board | 1 | $3.00 | $3.00 | Do not skip this on lithium. |
| 14 | 100 kΩ resistor (battery divider) | 2 | $0.10 | $0.20 | 2:1 divider into `PIN_BATTERY_ADC`. |
| | **Subtotal (battery build)** | | | **$19.70** | |

## Passives, wiring, hardware

| # | Part | Qty | Unit | Total | Notes |
|---|---|---|---|---|---|
| 15 | 470 µF 10 V electrolytic capacitor | 1 | $0.30 | $0.30 | Across the servo 5 V rail. Cheapest fix for random reboots. |
| 16 | 100 nF ceramic capacitor | 2 | $0.10 | $0.20 | Decoupling at the mic and amp. |
| 17 | Dupont jumper wires, 20 cm F-F | 40 | $0.05 | $2.00 | For the bench. Solder before you close the body. |
| 18 | 22 AWG silicone hookup wire, 3 colours | 1 | $4.00 | $4.00 | Power and servo runs. |
| 19 | Heat-shrink assortment | 1 | $2.00 | $2.00 | |
| 20 | M3 × 10 screws + nuts | 12 | $0.05 | $0.60 | |
| 21 | M2 × 6 self-tapping screws | 16 | $0.03 | $0.48 | |
| 22 | M2.5 × 6 self-tapping screws | 4 | $0.03 | $0.12 | |
| 23 | Slide switch, SPST | 1 | $0.50 | $0.50 | Main power. |
| | **Subtotal** | | | **$10.20** | |

## Filament

| # | Part | Qty | Unit | Total | Notes |
|---|---|---|---|---|---|
| 24 | PLA filament | 180 g | $0.02/g | $3.60 | Body, head, most parts. |
| 25 | PETG filament | 40 g | $0.025/g | $1.00 | Drive wheels, neck bracket. |
| 26 | TPU 95A filament | 25 g | $0.04/g | $1.00 | The two track belts. |
| | **Subtotal** | | | **$5.60** | |

## Totals

| Build | Parts | Cost |
|---|---|---|
| Voice assistant only | 1–6, 10a, 15–19 | **$41.50** |
| Full robot, USB powered | 1–9, 10a, 15–26 | **$63.30** |
| Full robot, battery powered | everything | **$83.00** |

These add up from [`bom.csv`](bom.csv), which is checked by
`docs/check_bom.py` — every line's `qty × unit` must equal its `total`, and the
group subtotals must match this table.

## The server

The server needs a machine that is on when you want to talk to the robot. Rough
guide, measured on the pipeline in this repo (see
[`04-latency.md`](04-latency.md)):

| Machine | Wake→speech | Notes |
|---|---|---|
| Mac Mini M2 / M4 | **0.9–1.4 s** | The sweet spot. Whisper uses Metal, Ollama uses the ANE/GPU. Idles at ~7 W. |
| Any PC with an NVIDIA GPU (≥ 6 GB) | 0.7–1.2 s | Fastest option. Use `faster-whisper` here, not whisper.cpp. |
| Modern laptop, CPU only | 1.8–3.0 s | Perfectly usable. Use `base.en` and a 3B model. |
| Raspberry Pi 5, 8 GB | 4–8 s | Works for STT and TTS. Too slow for a local LLM — point `WALLE_LLM_BACKEND` at a cloud API or another machine. |
| Raspberry Pi 4 | — | Not recommended. Whisper alone eats the whole board. |

If you are buying a machine for this, a used Mac Mini M1/M2 with 16 GB is the
best value: it runs the whole stack locally, silently, on about as much power as
a lightbulb.

## Things you do *not* need

Worth stating, because comparable projects list them:

- **No I2S DAC breakout.** The MAX98357A is amplifier and DAC in one.
- **No motor driver board.** Continuous-rotation servos take PWM directly.
- **No level shifters.** Everything here is 3.3 V logic. (The MAX98357A takes
  5 V *power* and 3.3 V *logic* — that is fine and intended.)
- **No SD card.** Models live on the server; the firmware fits in flash.
- **No microphone array.** One INMP441 plus the pre-roll buffer and
  server-side recognition is enough at desk distance. An array only earns its
  place across a room.

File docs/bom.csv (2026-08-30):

# SPDX-License-Identifier: MIT
# Wall-E desk robot - bill of materials. Prices are indicative USD | early 2026.
# group: core = required; motion/power/passives/hardware/filament = see docs/01-parts-list.md
item | group | part | qty | unit_price_usd | total_usd | required | notes
1 | core | Freenove ESP32-S3-WROOM CAM board (8MB PSRAM + OV2640) | 1 | 16.00 | 16.00 | yes | Default pin map in firmware/include/config.h targets this board
2 | core | INMP441 I2S MEMS microphone module | 1 | 3.50 | 3.50 | yes | Digital mic keeps servo noise out of the audio
3 | core | MAX98357A I2S class-D amplifier | 1 | 4.50 | 4.50 | yes | Amplifier and DAC in one
4 | core | Speaker 4 ohm 3 W 40 mm | 1 | 3.00 | 3.00 | yes | 4-8 ohm fits the printed grille
5 | core | SSD1306 OLED 0.96in 128x64 I2C | 1 | 4.00 | 4.00 | yes | head_shell.stl window is cut for this module
6 | core | USB cable for flashing | 1 | 2.00 | 2.00 | yes
7 | motion | FS90R continuous-rotation micro servo | 2 | 5.00 | 10.00 | no | Continuous rotation - not standard servos
8 | motion | SG90 standard micro servo (head pan) | 1 | 2.50 | 2.50 | no | 180 degree
9 | motion | 6 mm x 60 mm steel rod or M6 bolt | 2 | 1.00 | 2.00 | no | Wheel axles
10 | power | 18650 Li-ion cell (protected) | 2 | 6.00 | 12.00 | no | 2S = 7.4 V nominal; skip for USB-only builds
11 | power | 2S 18650 battery holder | 1 | 2.50 | 2.50 | no
12 | power | MP1584EN or LM2596 buck converter | 1 | 2.00 | 2.00 | no | Set to 5.0 V before connecting anything
13 | power | 2S BMS / balance charge board | 1 | 3.00 | 3.00 | no | Do not skip on lithium
14 | power | 100k ohm resistor (battery divider) | 2 | 0.10 | 0.20 | no | 2:1 divider into PIN_BATTERY_ADC
15 | passives | 470 uF 10 V electrolytic capacitor | 1 | 0.30 | 0.30 | yes | Across the servo 5 V rail; fixes random reboots
16 | passives | 100 nF ceramic capacitor | 2 | 0.10 | 0.20 | yes | Decoupling at the mic and amp
17 | passives | Dupont jumper wires 20 cm F-F | 40 | 0.05 | 2.00 | yes
18 | passives | 22 AWG silicone hookup wire (3 colours) | 1 | 4.00 | 4.00 | yes
19 | passives | Heat-shrink assortment | 1 | 2.00 | 2.00 | yes
20 | hardware | M3 x 10 mm screw + nut | 12 | 0.05 | 0.60 | no
21 | hardware | M2 x 6 mm self-tapping screw | 16 | 0.03 | 0.48 | no
22 | hardware | M2.5 x 6 mm self-tapping screw | 4 | 0.03 | 0.12 | no
23 | hardware | SPST slide switch | 1 | 0.50 | 0.50 | no | Main power
24 | filament | PLA filament (grams) | 180 | 0.02 | 3.60 | no | Body head and most parts
25 | filament | PETG filament (grams) | 40 | 0.025 | 1.00 | no | Drive wheels and neck bracket
26 | filament | TPU 95A filament (grams) | 25 | 0.04 | 1.00 | no | Two track belts

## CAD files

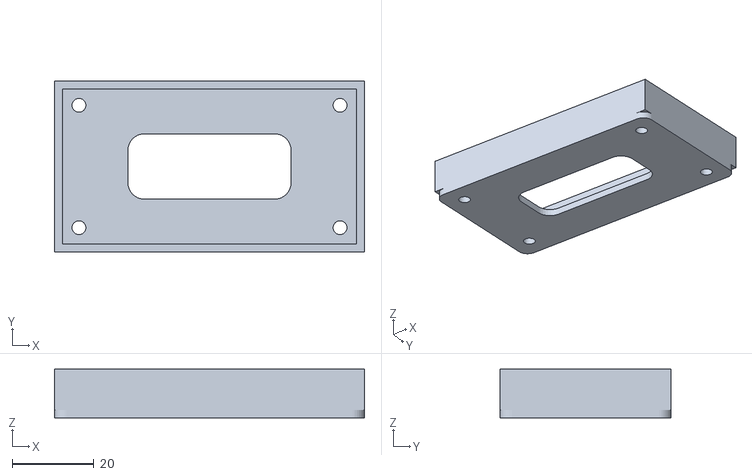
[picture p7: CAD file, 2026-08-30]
3d-models/stl/battery_tray.stl
76.0 x 42.0 x 12.0

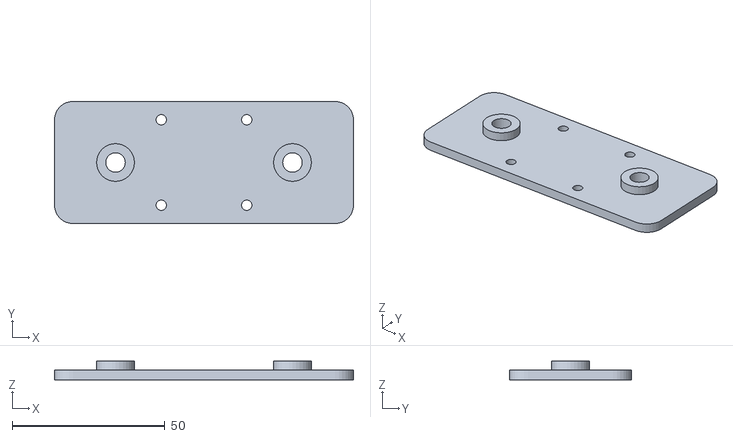
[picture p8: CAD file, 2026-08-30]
3d-models/stl/track_frame.stl
98.0 x 40.0 x 6.20

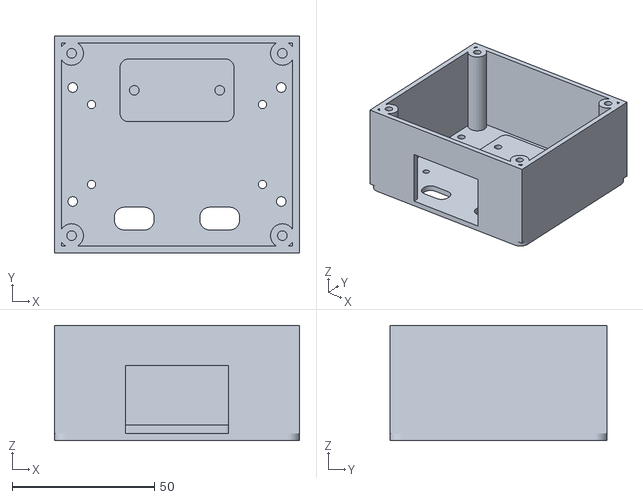
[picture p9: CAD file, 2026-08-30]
3d-models/stl/chassis_base.stl
86.0 x 76.0 x 40.4

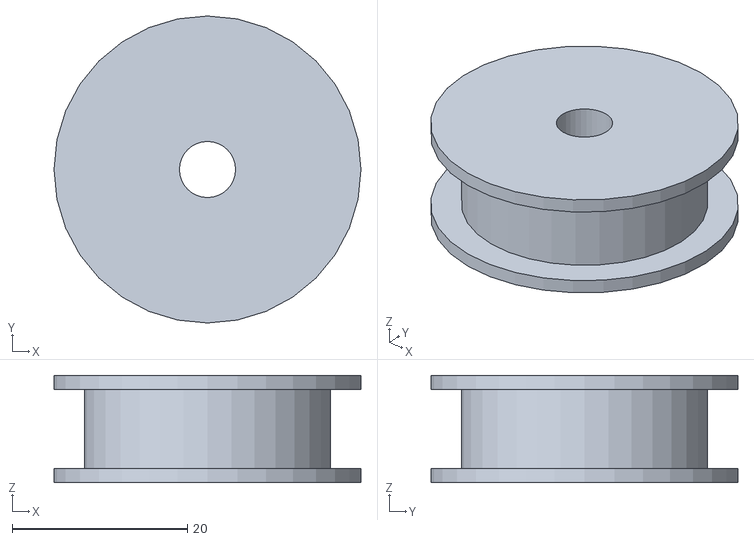
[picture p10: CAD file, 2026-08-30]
3d-models/stl/idler_wheel.stl
35.0 x 35.0 x 12.2

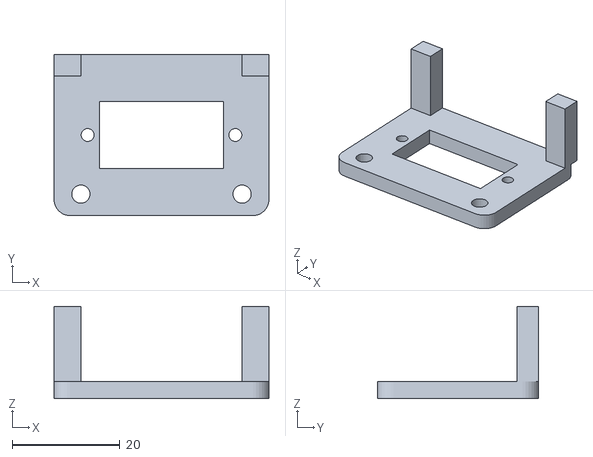
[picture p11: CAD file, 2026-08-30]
3d-models/stl/neck_bracket.stl
40.0 x 30.0 x 17.2

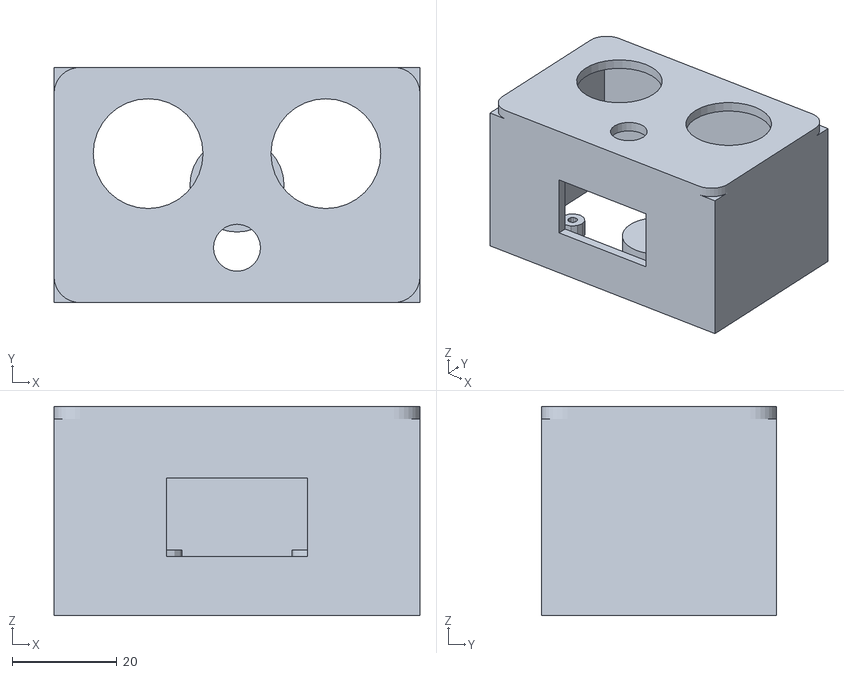
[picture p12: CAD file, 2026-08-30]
3d-models/stl/head_shell.stl
70.0 x 45.0 x 40.0

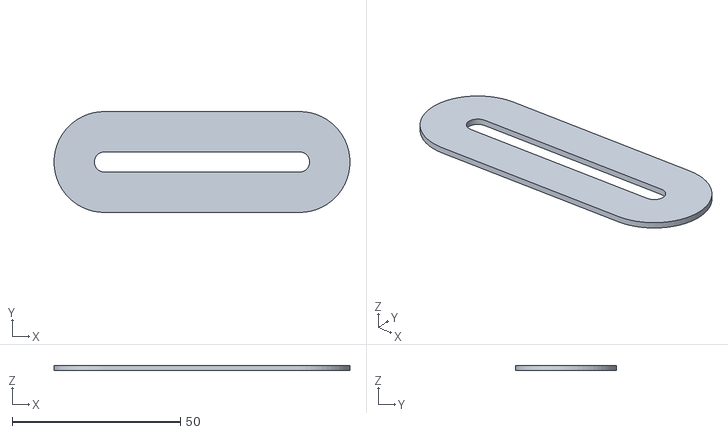
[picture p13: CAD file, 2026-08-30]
3d-models/stl/track_belt.stl
88.0 x 30.0 x 1.60

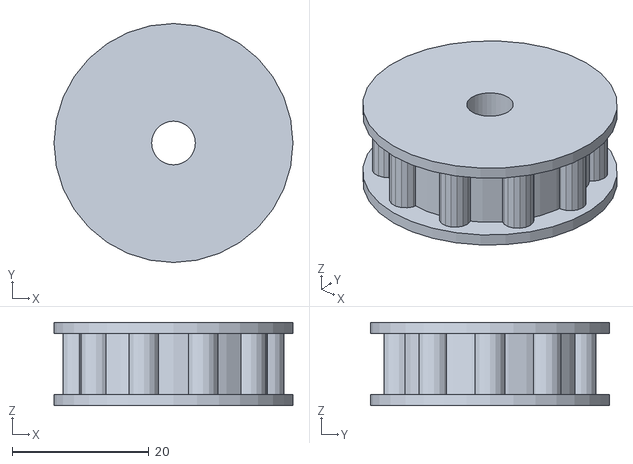
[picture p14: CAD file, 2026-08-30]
3d-models/stl/drive_wheel.stl
35.0 x 35.0 x 12.2

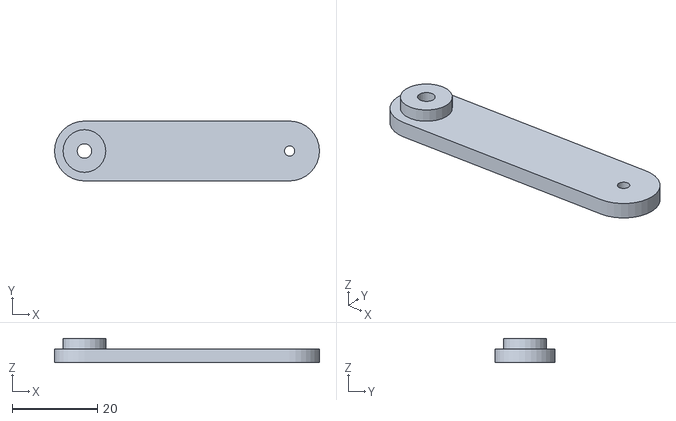
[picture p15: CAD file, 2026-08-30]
3d-models/stl/arm.stl
62.0 x 14.0 x 5.70

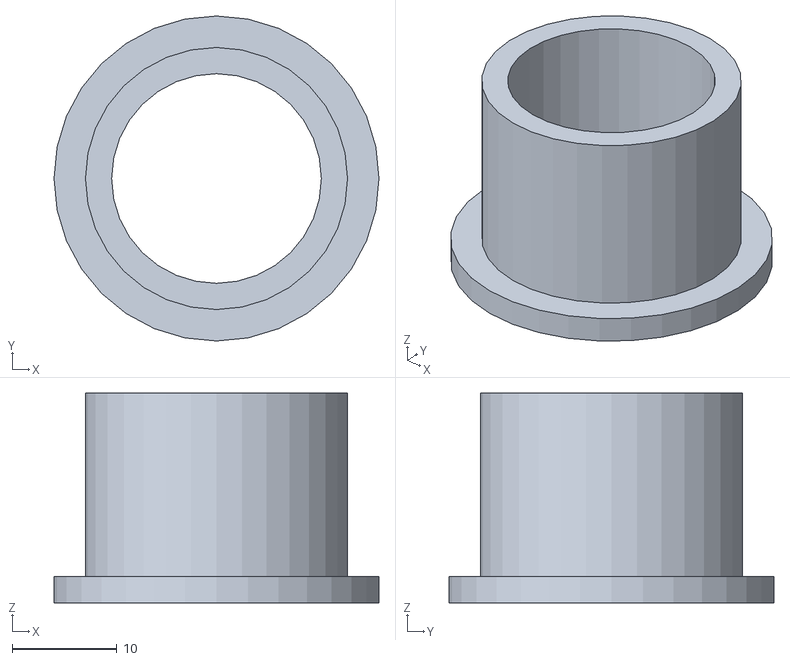
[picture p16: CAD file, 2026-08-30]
3d-models/stl/eye_pod.stl
31.0 x 31.0 x 20.0

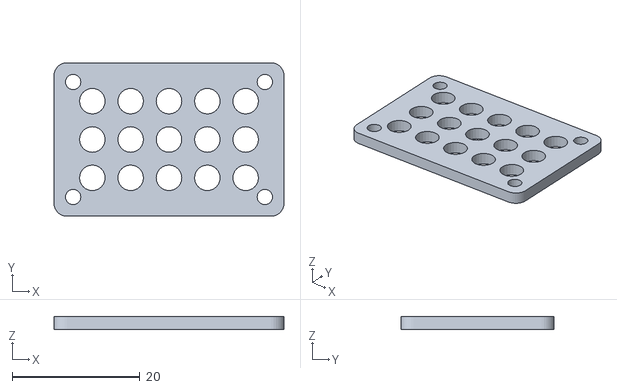
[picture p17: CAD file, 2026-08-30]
3d-models/stl/speaker_grille.stl
36.0 x 24.0 x 2.00

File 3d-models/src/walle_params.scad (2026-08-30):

// SPDX-License-Identifier: MIT
// Shared dimensions for every Wall-E part.
//
// These names and values match 3d-models/tools/gen_stl.py exactly. If you
// change something here, change it there too (or just regenerate from these
// files with OpenSCAD and ignore the Python generator entirely - it exists
// only so the repo ships STLs for people without OpenSCAD installed).

$fn = 48;                   // facets on curves; 48 is smooth at this scale

// ---- general -------------------------------------------------------------
wall        = 2.4;          // 6 perimeters at a 0.4 mm nozzle
floor_t     = 2.4;
clearance   = 0.3;          // between mating printed parts

// ---- body ----------------------------------------------------------------
body_w      = 86;           // left-right, inside the track frames
body_d      = 76;           // front-back
body_h      = 38;           // floor to open top

// ---- head ----------------------------------------------------------------
head_w      = 70;
head_d      = 45;
head_h      = 40;
oled_win_w  = 27;           // visible area of a 0.96" SSD1306
oled_win_h  = 15;

// ---- fasteners -----------------------------------------------------------
// Radii, already oversized ~0.2 mm because FDM printers shrink holes.
m2          = 1.2;
m25         = 1.45;
m3          = 1.7;
axle        = 3.2;          // 6 mm axle / M6 shank

// ---- drive ---------------------------------------------------------------
wheel_r     = 16;
wheel_h     = 9;
wheel_gap   = 58;           // drive-to-idler centre distance
belt_w      = 12;
belt_t      = 1.6;

// ---- servos --------------------------------------------------------------
// SG90 / MG90S / FS90R all share this body.
servo_body  = [23, 12.5, 22.5];
servo_screw_pitch = 27.5;

// Convenience: a rounded slab, the shape most of these parts start from.
module slab(size, r = 3) {
    linear_extrude(height = size[2])
        offset(r = r) offset(r = -r)
            square([size[0], size[1]]);
}

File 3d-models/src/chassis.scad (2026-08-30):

// SPDX-License-Identifier: MIT
// Body: the tub that holds the ESP32, the battery and the drive servos.
//
//   openscad -o ../stl/chassis_base.stl -D 'part="chassis_base"' chassis.scad
//
// Everything prints without support. The front opening is a rectangle rather
// than a grille so nothing has to bridge; the grille is a separate flat part.

include <walle_params.scad>

part = "chassis_base";   // chassis_base | speaker_grille | battery_tray

if (part == "chassis_base")      chassis_base();
else if (part == "speaker_grille") speaker_grille();
else if (part == "battery_tray")   battery_tray();

module chassis_base() {
    speaker_open = [36, 24];
    difference() {
        union() {
            // Floor slab.
            slab([body_w, body_d, floor_t], 4);
            // Perimeter walls, with a gap left for the speaker opening.
            difference() {
                translate([0, 0, floor_t])
                    difference() {
                        slab([body_w, body_d, body_h], 4);
                        translate([wall, wall, -1])
                            cube([body_w - 2 * wall, body_d - 2 * wall, body_h + 2]);
                    }
                // Speaker opening in the front wall.
                translate([(body_w - speaker_open[0]) / 2, -1, floor_t])
                    cube([speaker_open[0], wall + 2, speaker_open[1]]);
            }
            // Lid screw bosses.
            for (p = [[6, 6], [body_w - 6, 6], [6, body_d - 6], [body_w - 6, body_d - 6]])
                translate([p[0], p[1], floor_t]) cylinder(h = body_h, r = 4.2);
            // Raised pad the neck bracket bolts to.
            translate([body_w / 2 - 20, body_d - 30, floor_t])
                slab([40, 22, 3], 3);
        }

        // --- everything removed below ---
        // ESP32-S3 board mounts, 60 x 28 pattern.
        for (dx = [-30, 30], dy = [-14, 14])
            translate([body_w / 2 + dx, body_d / 2 + dy, -1])
                cylinder(h = floor_t + 2, r = m25);
        // Cable pass-throughs.
        for (dx = [-15, 15])
            translate([body_w / 2 + dx - 7, 8, -1])
                hull() for (x = [0, 14]) translate([x, 4, 0]) cylinder(h = floor_t + 2, r = 4);
        // Track frame bolts.
        for (x = [wall + 4, body_w - wall - 4], y = [18, body_d - 18])
            translate([x, y, -1]) cylinder(h = floor_t + 2, r = m3);
        // Lid screw holes through the bosses.
        for (p = [[6, 6], [body_w - 6, 6], [6, body_d - 6], [body_w - 6, body_d - 6]])
            translate([p[0], p[1], -1]) cylinder(h = body_h + floor_t + 2, r = m3);
        // Neck bracket bolts.
        for (dx = [-15, 15])
            translate([body_w / 2 + dx, body_d - 19, -1])
                cylinder(h = floor_t + 6, r = m3);
    }
}

module speaker_grille() {
    difference() {
        slab([36, 24, 2], 2);
        for (row = [0 : 2], col = [0 : 4])
            translate([6 + col * 6, 6 + row * 6, -1]) cylinder(h = 4, r = 2);
        for (x = [3, 33], y = [3, 21])
            translate([x, y, -1]) cylinder(h = 4, r = m2);
    }
}

module battery_tray() {
    difference() {
        union() {
            slab([76, 42, 2], 3);
            difference() {
                translate([0, 0, 2]) slab([76, 42, 10], 3);
                translate([2, 2, 1]) cube([72, 38, 12]);
            }
        }
        // Weight-saving window and mounting holes.
        translate([76 / 2 - 20, 42 / 2 - 8, -1]) slab([40, 16, 4], 4);
        for (x = [6, 70], y = [6, 36]) translate([x, y, -1]) cylinder(h = 4, r = m3);
    }
}

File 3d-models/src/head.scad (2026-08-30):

// SPDX-License-Identifier: MIT
// Head, eye pods, neck bracket and arms.
//
//   openscad -o ../stl/head_shell.stl -D 'part="head_shell"' head.scad
//
// The head prints open-face-down. The OLED window has no bridge over it
// because the front wall is split above and below the opening.

include <walle_params.scad>

part = "head_shell";  // head_shell | eye_pod | neck_bracket | arm

if (part == "head_shell")        head_shell();
else if (part == "eye_pod")      eye_pod();
else if (part == "neck_bracket") neck_bracket();
else if (part == "arm")          arm();

module head_shell() {
    difference() {
        union() {
            // Shell: outer slab hollowed from below.
            difference() {
                slab([head_w, head_d, head_h], 5);
                translate([wall, wall, -1])
                    cube([head_w - 2 * wall, head_d - 2 * wall, head_h - wall + 1]);
            }
            // Neck socket for the servo horn.
            translate([head_w / 2, head_d / 2, 0]) cylinder(h = 5, r = 9);
            // Bosses to screw the OLED module in from behind.
            for (dx = [-13.5, 13.5], dz = [-9.5, 9.5])
                translate([head_w / 2 + dx, wall + 3, head_h / 2 + dz])
                    rotate([90, 0, 0]) cylinder(h = 4, r = 3, center = true);
        }

        // Display window.
        translate([(head_w - oled_win_w) / 2, -1, (head_h - wall - oled_win_h) / 2])
            cube([oled_win_w, wall + 2, oled_win_h]);
        // Eye pod holes and the camera hole in the roof.
        for (dx = [-17, 17])
            translate([head_w / 2 + dx, head_d / 2 + 6, head_h - wall - 1])
                cylinder(h = wall + 2, r = 10.5);
        translate([head_w / 2, head_d / 2 - 12, head_h - wall - 1])
            cylinder(h = wall + 2, r = 4.5);
        // Servo horn screw.
        translate([head_w / 2, head_d / 2, -1]) cylinder(h = 8, r = 3);
        // OLED boss pilot holes.
        for (dx = [-13.5, 13.5], dz = [-9.5, 9.5])
            translate([head_w / 2 + dx, wall + 5, head_h / 2 + dz])
                rotate([90, 0, 0]) cylinder(h = 8, r = m2, center = true);
    }
}

module eye_pod() {
    difference() {
        union() {
            cylinder(h = 20, r = 12.5);
            cylinder(h = 2.5, r = 15.5);   // flange, sits on the roof
        }
        translate([0, 0, -1]) cylinder(h = 24, r = 10);
    }
}

module neck_bracket() {
    w = 40; d = 30; t = 3.2;
    difference() {
        union() {
            slab([w, d, t], 3);
            for (x = [0, w - 5]) translate([x, d - 4, t]) cube([5, 4, 14]);
        }
        // Servo body pocket and its flange screws.
        translate([w / 2 - servo_body[0] / 2, d / 2 - servo_body[1] / 2, -1])
            cube([servo_body[0], servo_body[1], t + 2]);
        for (dx = [-servo_screw_pitch / 2, servo_screw_pitch / 2])
            translate([w / 2 + dx, d / 2, -1]) cylinder(h = t + 2, r = m2);
        // Bolts down to the chassis pad.
        for (dx = [-15, 15]) translate([w / 2 + dx, 4, -1]) cylinder(h = t + 2, r = m3);
    }
}

module arm() {
    l = 62; w = 14; t = 3.2;
    difference() {
        union() {
            slab([l, w, t], w / 2);
            translate([7, w / 2, t]) cylinder(h = 2.5, r = 5);  // shoulder boss
        }
        translate([7, w / 2, -1]) cylinder(h = t + 8, r = m3);
        translate([l - 7, w / 2, -1]) cylinder(h = t + 2, r = m2);
    }
}

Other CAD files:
3d-models/src/tracks.scad

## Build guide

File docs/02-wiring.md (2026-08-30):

# Wiring

Wall-E wiring diagram

Every pin number below is a **GPIO number** and matches
[`firmware/include/config.h`](../firmware/include/config.h). If you change one,
change it there — nothing else in the firmware hard-codes a pin.

## Pin map

### Microphone — INMP441 (I2S peripheral 0)

| INMP441 | ESP32-S3 | Notes |
|---|---|---|
| VDD | 3V3 | Not 5 V. This part is 3.3 V only. |
| GND | GND | |
| SCK | GPIO 39 | Bit clock |
| WS | GPIO 38 | Word select / LR clock |
| SD | GPIO 40 | Data out of the mic, into the ESP32 |
| L/R | **GND** | Ties the mic to the left channel, which is what the firmware reads |

Leaving L/R floating is the single most common cause of "the mic returns
silence". It must go to GND.

### Speaker — MAX98357A (I2S peripheral 1)

| MAX98357A | ESP32-S3 | Notes |
|---|---|---|
| VIN | **5 V** | From the buck converter, not the 3V3 pin |
| GND | GND | |
| BCLK | GPIO 41 | |
| LRC | GPIO 42 | |
| DIN | GPIO 21 | |
| GAIN | *leave floating* | 9 dB. Tie to GND for 12 dB if you want it louder. |
| SD | *leave floating* | Pulled high internally = always on |
| + / − | Speaker | 4–8 Ω. No polarity, no series capacitor. |

Two separate I2S peripherals is why the robot can listen and speak at the same
time, which is what makes barge-in possible.

### Display — SSD1306 OLED

| OLED | ESP32-S3 |
|---|---|
| VCC | 3V3 |
| GND | GND |
| SDA | GPIO 47 |
| SCL | GPIO 48 |

This is a **separate I2C bus** from the camera's SCCB lines (GPIO 4/5). Do not
share them — the camera driver reconfigures that bus and your face will freeze.

If the display stays blank, the address is the usual culprit: most modules are
`0x3C`, some are `0x3D`. Change `OLED_I2C_ADDR` in `config.h`.

### Servos

| Servo | Signal | Power |
|---|---|---|
| Left track (FS90R, continuous rotation) | GPIO 2 | 5 V rail |
| Right track (FS90R, continuous rotation) | GPIO 3 | 5 V rail |
| Head pan (SG90, standard 180°) | GPIO 14 | 5 V rail |

Servo red wires go to the **5 V rail**, never to the ESP32's 3V3 pin. A stalled
FS90R pulls close to an amp; the ESP32's regulator will shut down long before
that and you will spend an evening blaming your Wi-Fi.

### Battery sensing

```
BATT+ ──[100 kΩ]──┬──[100 kΩ]── GND
                  │
               GPIO 1 (ADC1_CH0)
```

A 2:1 divider, so a 8.4 V full pack reads 4.2 V — comfortably inside ADC1's
range with 12 dB attenuation. If you use different resistors, update
`BATTERY_DIVIDER_RATIO` in `config.h`.

Use ADC**1** pins only (GPIO 1–10). ADC2 shares hardware with the Wi-Fi radio
and returns garbage whenever the radio is active.

### Camera

The OV2640 is wired on the board. It occupies GPIO 4, 5, 6, 7, 8, 9, 10, 11,
12, 13, 15, 16, 17 and 18. **Do not reuse any of them.** They are listed in
`config.h` under "camera pins (fixed)" so you can see at a glance what is taken.

### Button

The board's BOOT button is on GPIO 0 with an internal pull-up. The firmware
uses it for push-to-talk (tap) and reboot (hold 3 s). No extra wiring.

## Power

```
2S 18650 pack (6.0–8.4 V)
   │
   ├── BMS / balance charger
   │
   └── buck converter, set to 5.00 V BEFORE connecting anything
          │
          ├── ESP32-S3  5V pin
          ├── MAX98357A VIN
          └── all three servos
```

Three things that are not optional:

1. **Set the buck converter's output voltage before you connect the ESP32.**
   These boards ship at whatever the last person left the trimmer at. Measure
   it. 6 V will destroy the board.
2. **470 µF across the 5 V rail, physically close to the servos.** Servos draw
   current in sharp pulses; without bulk capacitance those pulses drop the rail
   far enough to reset the ESP32. If your robot reboots whenever it moves, this
   is why.
3. **One common ground.** Battery negative, buck ground, ESP32 GND, mic GND, amp
   GND, servo browns — all one node. I2S is a synchronous protocol and a ground
   offset of a few hundred millivolts turns clean audio into noise.

USB-only builds skip all of this: plug the board into a USB port and connect the
servos' red wires to the board's 5 V pin. A USB 3 port supplies plenty for three
micro servos that only run in short bursts.

## Bench bring-up order

Do not wire everything and then power it on. Build it up in stages, and flash
the `walle-minimal` environment first — it disables the camera, the motors and
the wake word so there is less to go wrong:

```bash
cd firmware && pio run -e walle-minimal -t upload && pio device monitor
```

1. **Board alone.** Confirm it boots and joins Wi-Fi. The serial log prints the
   IP address.
2. **Add the OLED.** You should get a face. If not, it is the address or SDA/SCL
   are swapped.
3. **Add the microphone.** Tap BOOT and watch the level meter move when you
   speak. `[voice] listening` appears in the log.
4. **Add the amplifier and speaker.** You should hear the two-tone wake chirp
   when you tap BOOT.
5. **Add the servos**, one at a time, on external 5 V. Trim `SERVO_LEFT_STOP_US`
   and `SERVO_RIGHT_STOP_US` until the tracks are genuinely still at idle —
   continuous-rotation servos are never exactly centred at 1500 µs.
6. **Switch to the full build** (`pio run -t upload`) to bring up the camera and
   the wake word.

Each stage takes two minutes and saves an hour of staring at a robot that does
nothing.

## Troubleshooting

| Symptom | Cause |
|---|---|
| Mic returns silence | L/R pin not tied to GND; or SD wired to the wrong GPIO |
| Audio is noisy or buzzes | Grounds not common; or the mic wires run alongside servo wires |
| Robot reboots when it moves | Missing 470 µF; or servos on the 3V3 rail |
| OLED blank | Wrong I2C address (`0x3C` vs `0x3D`); or SDA/SCL swapped |
| OLED freezes when the camera runs | OLED is sharing the camera's SCCB bus — move it to 47/48 |
| Camera init fails | PSRAM not enabled — check `-DBOARD_HAS_PSRAM` is in `build_flags` |
| Tracks creep when idle | Trim `SERVO_*_STOP_US`, a few µs at a time |
| One track runs backwards | Flip `SERVO_LEFT_INVERT` or `SERVO_RIGHT_INVERT` |
| Battery reads 0 mV | Divider on an ADC2 pin — it must be GPIO 1–10 |

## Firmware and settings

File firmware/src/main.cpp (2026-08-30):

// SPDX-License-Identifier: MIT
// ---------------------------------------------------------------------------
// Wall-E desk robot - main orchestration loop.
//
// Design in one paragraph: the microphone is the clock. audio_in::readFrame()
// blocks until the I2S DMA has exactly 20 ms of audio, so the loop below runs
// at a steady 50 Hz without a single delay() call, and every subsystem gets
// serviced between frames. The ESP32 does only what an ESP32 is good at -
// capturing audio, detecting the wake word offline, moving servos, drawing a
// face - and ships everything else to the server over one WebSocket.
//
// State machine:
//
//   BOOT -> CONNECTING -> IDLE <-> LISTENING -> THINKING -> SPEAKING
//                          ^                                    |
//                          +------------------------------------+
//
// Anything can drop back to CONNECTING if the link dies, and to UPDATING when
// an OTA starts.
// ---------------------------------------------------------------------------
#include <Arduino.h>

#include "config.h"
#include "core/protocol.h"
#include "hal/audio_in.h"
#include "hal/audio_out.h"
#include "hal/camera.h"
#include "hal/display.h"
#include "hal/motors.h"
#include "hal/power.h"
#include "net/ota.h"
#include "net/wifi_manager.h"
#include "net/ws_link.h"
#include "secrets.h"
#include "voice/vad.h"
#include "voice/wakeword.h"

namespace {

enum State : uint8_t {
  ST_BOOT,
  ST_CONNECTING,
  ST_IDLE,
  ST_LISTENING,
  ST_THINKING,
  ST_SPEAKING,
  ST_UPDATING,
};

State gState = ST_BOOT;
uint32_t gStateSince = 0;

int16_t gFrame[WALLE_AUDIO_FRAME_SAMPLES];
uint32_t gUttStart = 0;
bool gWakewordAvailable = false;

// Button (BOOT) handling: short press = push to talk, 3 s hold = reboot.
bool gBtnDown = false;
uint32_t gBtnDownAt = 0;
bool gBtnConsumed = false;

uint32_t gLastStateReport = 0;
uint32_t gUnmuteAt = 0;      // re-arm the wake word after Wall-E stops talking
bool gPendingOta = false;
char gOtaUrl[192] = {0};

// The server sets this while it is streaming speech; we only leave SPEAKING
// once the server has said it is done AND the local buffer has drained.
bool gServerSaidDone = true;

const char *stateName(State s) {
  switch (s) {
    case ST_BOOT: return "boot";
    case ST_CONNECTING: return "connecting";
    case ST_IDLE: return "idle";
    case ST_LISTENING: return "listening";
    case ST_THINKING: return "thinking";
    case ST_SPEAKING: return "speaking";
    case ST_UPDATING: return "updating";
  }
  return "?";
}

void setState(State s) {
  if (gState == s) return;
  gState = s;
  gStateSince = millis();

  switch (s) {
    case ST_CONNECTING:
      display::setExpression(EXPR_SLEEP);
      display::setStatusLine("connecting");
      break;
    case ST_IDLE:
      display::setExpression(EXPR_IDLE);
      display::setStatusLine(nullptr);
      wakeword::setMuted(false);
      break;
    case ST_LISTENING:
      display::setExpression(EXPR_LISTENING);
      break;
    case ST_THINKING:
      display::setExpression(EXPR_THINKING);
      break;
    case ST_SPEAKING:
      display::setExpression(EXPR_SPEAKING);
      break;
    default:
      break;
  }
  Serial.printf("[state] -> %s\n", stateName(s));
}

// --------------------------- utterance capture -----------------------------

void beginUtterance(const char *reason) {
  if (!ws_link::isConnected()) return;

  // Acknowledge instantly. The chirp plays from local memory in a couple of
  // milliseconds, so the user gets feedback long before the server has done
  // anything. This one line is worth more perceived responsiveness than any
  // amount of pipeline tuning.
  audio_out::playWakeChirp();

  vad::reset();
  gUttStart = millis();
  ws_link::sendUttBegin();

  // Ship the pre-roll first so the recogniser hears the whole sentence,
  // including the syllables spoken before the wake word finished scoring.
  static int16_t preroll[(WALLE_AUDIO_SAMPLE_RATE * VOICE_PREROLL_MS) / 1000];
  const size_t n = audio_in::copyPreroll(preroll, sizeof(preroll) / sizeof(preroll[0]));
  for (size_t off = 0; off < n; off += WALLE_AUDIO_FRAME_SAMPLES) {
    const size_t chunk = (n - off) > WALLE_AUDIO_FRAME_SAMPLES
                             ? WALLE_AUDIO_FRAME_SAMPLES
                             : (n - off);
    ws_link::sendAudio(preroll + off, chunk,
                       off == 0 ? WALLE_FLAG_FIRST : WALLE_FLAG_NONE);
  }

  setState(ST_LISTENING);
  Serial.printf("[voice] listening (%s), preroll %u samples\n", reason, (unsigned)n);
}

void endUtterance(bool speechDetected) {
  const uint32_t ms = millis() - gUttStart;
  ws_link::sendAudio(nullptr, 0, WALLE_FLAG_LAST);
  ws_link::sendUttEnd(ms, speechDetected);

  if (!speechDetected) {
    // Nothing but silence: almost certainly a false wake. Don't make the
    // server pay for a transcription, just go back to sleep.
    display::setExpression(EXPR_CONFUSED, 700);
    setState(ST_IDLE);
    Serial.println("[voice] no speech, discarding");
    return;
  }
  setState(ST_THINKING);
}

// ------------------------- server message handling -------------------------

void handleControl(const char *type, JsonObjectConst msg) {
  if (!strcmp(type, MSG_HELLO_ACK)) {
    const int proto = msg["proto"] | 0;
    if (proto != WALLE_PROTO_VERSION) {
      Serial.printf("[link] protocol mismatch: server=%d device=%d\n",
                    proto, WALLE_PROTO_VERSION);
      display::showBanner("Version mismatch", "update firmware");
      return;
    }
    Serial.println("[link] server ready");
    setState(ST_IDLE);

  } else if (!strcmp(type, MSG_FACE)) {
    const Expression e = display::expressionFromName(msg["e"] | "");
    if (e != EXPR_COUNT) {
      display::setExpression(e, msg["ms"] | 0);
    }

  } else if (!strcmp(type, MSG_SAY_BEGIN)) {
    gServerSaidDone = false;
    // Mute the wake word while we talk, or Wall-E hears himself say "Wall-E"
    // and wakes up in an infinite loop. (Ask how we know.)
    wakeword::setMuted(true);
    setState(ST_SPEAKING);
    const char *text = msg["text"] | "";
    if (*text) Serial.printf("[say] %s\n", text);

  } else if (!strcmp(type, MSG_SAY_END)) {
    gServerSaidDone = true;

  } else if (!strcmp(type, MSG_TURN_END)) {
    // The server is finished with this turn. If it never sent any speech - it
    // heard nothing intelligible, or an engine failed - this is what gets us
    // out of THINKING immediately instead of waiting for the 20 s timeout.
    if (gState == ST_THINKING) {
      gServerSaidDone = true;
      setState(ST_IDLE);
    }

  } else if (!strcmp(type, MSG_MOVE)) {
    const MoveCmd cmd = motors::cmdFromName(msg["cmd"] | "stop");
    motors::move(cmd, msg["speed"] | 60, msg["ms"] | 0);

  } else if (!strcmp(type, MSG_HEAD)) {
    motors::setHead(msg["deg"] | 90);

  } else if (!strcmp(type, MSG_CAM)) {
#if WALLE_ENABLE_CAMERA
    if (!camera::isReady()) {
      ws_link::sendLog("warn", "camera not available");
      return;
    }
    const uint8_t q = msg["q"] | 12;
    camera::setQuality(q);
    size_t len = 0;
    uint16_t w = 0, h = 0;
    const uint8_t *jpeg = camera::capture(&len, &w, &h);
    if (jpeg) {
      ws_link::sendJpeg(jpeg, len, w, h);
      camera::release();
      Serial.printf("[cam] sent %ux%u, %u bytes\n", w, h, (unsigned)len);
    } else {
      ws_link::sendLog("error", "capture failed");
    }
#else
    ws_link::sendLog("warn", "camera disabled in this build");
#endif

  } else if (!strcmp(type, MSG_OTA)) {
    const char *url = msg["url"] | "";
    if (*url) {
      // Do not flash from inside the WebSocket callback - finish this loop
      // iteration first so the socket can close cleanly.
      strncpy(gOtaUrl, url, sizeof(gOtaUrl) - 1);
      gOtaUrl[sizeof(gOtaUrl) - 1] = '\0';
      gPendingOta = true;
    }

  } else if (!strcmp(type, MSG_ERROR)) {
    const char *m = msg["msg"] | "server error";
    Serial.printf("[link] error: %s\n", m);
    display::setExpression(EXPR_CONFUSED, 1500);
    if (gState == ST_THINKING || gState == ST_SPEAKING) setState(ST_IDLE);

  } else {
    Serial.printf("[link] unknown message '%s'\n", type);
  }
}

void handleAudio(const int16_t *samples, size_t count, uint8_t flags) {
  if (count) {
    const size_t accepted = audio_out::write(samples, count);
    if (accepted < count) {
      // Buffer full. Dropping the tail of a frame is inaudible; stalling the
      // WebSocket loop to wait for room is not.
      Serial.println("[audio] playback buffer full, dropped samples");
    }
  }
  if (flags & WALLE_FLAG_LAST) gServerSaidDone = true;
}

// ------------------------------- button ------------------------------------

void serviceButton() {
  // BOOT button is active-low with an internal pull-up.
  const bool down = (digitalRead(PIN_BUTTON) == LOW);
  const uint32_t now = millis();

  if (down && !gBtnDown) {
    gBtnDown = true;
    gBtnDownAt = now;
    gBtnConsumed = false;
  } else if (down && gBtnDown && !gBtnConsumed && (now - gBtnDownAt) > 3000) {
    gBtnConsumed = true;
    display::showBanner("Rebooting...");
    delay(300);
    ESP.restart();
  } else if (!down && gBtnDown) {
    gBtnDown = false;
    const uint32_t heldMs = now - gBtnDownAt;
    if (!gBtnConsumed && heldMs > 40) {  // 40 ms debounce
      if (gState == ST_IDLE) {
        beginUtterance("button");
      } else if (gState == ST_SPEAKING) {
        // Barge-in. Dropping the local buffer is not enough on its own: the
        // server keeps streaming the rest of the reply, which would simply be
        // buffered and played again. Starting a new utterance is what sends
        // utt_begin, and utt_begin is what cancels the server's speaking task.
        audio_out::flush();
        gServerSaidDone = true;
        wakeword::setMuted(false);
        gUnmuteAt = 0;
        // The pre-roll is full of Wall-E's own voice coming back through the
        // mic; sending it would give the recogniser the robot's words.
        audio_in::clearPreroll();
        beginUtterance("barge-in");
      }
    }
  }
}

// ---------------------------- periodic reporting ---------------------------

void reportState() {
  const uint32_t now = millis();
  if (now - gLastStateReport < STATE_REPORT_INTERVAL_MS) return;
  gLastStateReport = now;
  if (!ws_link::isConnected()) return;
  ws_link::sendState(stateName(gState), power::batteryMillivolts(),
                     power::batteryPercent(), wifi_manager::rssi());
}

void serviceBattery() {
  power::tick();
  // Critically low: motion is what actually browns out the board, so cut it
  // and let the voice assistant keep working.
  motors::setInhibited(power::isCritical());
  if (power::isCritical() && gState == ST_IDLE) {
    display::setStatusLine("battery low");
  }
}

}  // namespace

// --------------------------------- setup -----------------------------------

void setup() {
  Serial.begin(WALLE_SERIAL_BAUD);
  delay(200);
  Serial.printf("\nWall-E %s booting\n", WALLE_FW_VERSION);

  pinMode(PIN_BUTTON, INPUT_PULLUP);

  if (!display::begin()) Serial.println("[init] OLED not found (check SDA/SCL)");
  display::showBanner("Wall-E", "starting up");

  if (!power::begin()) Serial.println("[init] battery ADC failed");
  if (!motors::begin()) Serial.println("[init] servos failed");

  if (!audio_in::begin()) {
    Serial.println("[init] microphone failed - halting");
    display::showBanner("Mic failed", "check I2S wiring");
    // No microphone means no voice assistant. Sit here blinking rather than
    // pretending to work.
    while (true) {
      display::tick();
      delay(50);
    }
  }
  if (!audio_out::begin()) Serial.println("[init] speaker failed");

#if WALLE_ENABLE_CAMERA
  if (!camera::begin()) Serial.println("[init] camera failed (vision disabled)");
#endif

  gWakewordAvailable = wakeword::begin();
  Serial.printf("[init] wake word backend: %s\n",
                gWakewordAvailable ? wakeword::backendName() : "button only");

  display::showBanner("Wall-E", "joining wifi");
  if (wifi_manager::begin()) {
    Serial.printf("[init] wifi ok, ip=%s\n", wifi_manager::ipAddress());
  } else {
    Serial.println("[init] wifi timeout - will keep retrying");
  }

  ota::begin();
  ws_link::begin(handleControl, handleAudio);

  setState(ST_CONNECTING);
  Serial.println("[init] ready");
}

// ---------------------------------- loop -----------------------------------

void loop() {
  // 1. Audio first. This blocks for ~20 ms and is what paces the whole loop.
  const size_t got = audio_in::readFrame(gFrame);

  // 2. Service everything that must run regardless of state.
  wifi_manager::tick();
  ws_link::loop();
  ota::tick();
  motors::tick();
  serviceBattery();
  display::tick();
  serviceButton();
  audio_out::tick();
  reportState();

  if (gPendingOta) {
    gPendingOta = false;
    setState(ST_UPDATING);
    ota::pullUpdate(gOtaUrl);  // reboots on success
    setState(ST_IDLE);
    return;
  }
  if (ota::inProgress()) return;

  // Show the live input level while listening, and the output level while
  // talking, so the face always reflects what is actually happening.
  display::setAudioLevel(gState == ST_SPEAKING ? audio_out::level()
                                               : audio_in::lastLevelPercent());

  // 3. Link supervision. Anything below here needs a live server.
  if (!ws_link::isConnected()) {
    if (gState != ST_CONNECTING && gState != ST_UPDATING) {
      motors::stop();
      setState(ST_CONNECTING);
    }
    return;
  }

  if (got == 0) return;  // I2S hiccup; nothing else to do this round

  // 4. Wake-word detection runs on every frame in every state except while
  //    Wall-E is talking (wakeword::setMuted handles that internally).
  const bool woke = gWakewordAvailable && wakeword::feed(gFrame, got);

  // 5. State machine.
  switch (gState) {
    case ST_CONNECTING:
      // handleControl() moves us to IDLE when hello_ack lands.
      break;

    case ST_IDLE:
      if (woke) {
        ws_link::sendWake(wakeword::lastWord(), wakeword::lastScore());
        beginUtterance("wakeword");
      }
      break;

    case ST_LISTENING: {
      ws_link::sendAudio(gFrame, got, WALLE_FLAG_NONE);
      const bool done = vad::feedRms(audio_in::lastRms());
      if (done || vad::timedOut()) {
        endUtterance(vad::heardSpeech());
      }
      break;
    }

    case ST_THINKING:
      // The server owns this phase. Bail out if it goes quiet for too long so
      // the robot never gets stuck staring at the ceiling.
      if (millis() - gStateSince > 20000) {
        Serial.println("[link] server timed out");
        display::setExpression(EXPR_CONFUSED, 1500);
        setState(ST_IDLE);
      }
      break;

    case ST_SPEAKING:
      if (gServerSaidDone && !audio_out::busy()) {
        // Small guard band before re-arming the wake word: the speaker cone
        // and the room are still ringing for a few tens of milliseconds.
        if (gUnmuteAt == 0) {
          gUnmuteAt = millis() + 200;
        } else if (millis() >= gUnmuteAt) {
          gUnmuteAt = 0;
          audio_in::clearPreroll();  // drop our own voice from the pre-roll
          setState(ST_IDLE);
        }
      } else {
        gUnmuteAt = 0;
      }
      break;

    default:
      break;
  }
}

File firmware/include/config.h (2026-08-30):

// SPDX-License-Identifier: MIT
// ---------------------------------------------------------------------------
// Wall-E build configuration: pin map, tunables, feature switches.
//
// Everything a builder might reasonably want to change lives in this one file.
// Nothing secret goes here - Wi-Fi and server credentials belong in
// secrets.h (copy secrets.example.h, it is git-ignored).
//
// The default pin map targets the *Freenove ESP32-S3-WROOM CAM* board, because
// it is cheap, has 8 MB PSRAM (needed for camera frames + audio buffers) and
// still breaks out enough free GPIOs for two I2S buses, an OLED and servos.
// Camera pins on that board are hard-wired and must not be changed.
// ---------------------------------------------------------------------------
#pragma once

// ------------------------------- identity ---------------------------------
#define WALLE_DEVICE_NAME "walle-01"
#define WALLE_FW_VERSION "1.0.0"

// ------------------------------- features ---------------------------------
// Turn a subsystem off and its code drops out of the build. Useful for
// bring-up: get Wi-Fi + audio working before you solder the camera on.
//
// Every one is #ifndef-guarded so a PlatformIO env can override it with a -D
// flag. Without the guard these unconditional defines win over the command
// line, and the `walle-minimal` bring-up build would still compile in the
// camera and motors it promises to leave out.
#ifndef WALLE_ENABLE_CAMERA
#define WALLE_ENABLE_CAMERA 1
#endif
#ifndef WALLE_ENABLE_DISPLAY
#define WALLE_ENABLE_DISPLAY 1
#endif
#ifndef WALLE_ENABLE_MOTORS
#define WALLE_ENABLE_MOTORS 1
#endif
#ifndef WALLE_ENABLE_OTA
#define WALLE_ENABLE_OTA 1
#endif
#ifndef WALLE_ENABLE_BATTERY
#define WALLE_ENABLE_BATTERY 1
#endif

// Wake-word backend:
//   0 = push-to-talk only (BOOT button). Always compiles, zero dependencies.
//   1 = ESP-SR WakeNet ("Hi ESP" / "Alexa" models shipped by Espressif).
// See docs/03-research-notes.md for why ESP-SR wins on an S3.
#ifndef WALLE_WAKEWORD_BACKEND
#define WALLE_WAKEWORD_BACKEND 1
#endif

// --------------------------- camera pins (fixed) ---------------------------
// Freenove ESP32-S3-WROOM CAM / OV2640. Do not reassign.
#define CAM_PIN_PWDN -1
#define CAM_PIN_RESET -1
#define CAM_PIN_XCLK 15
#define CAM_PIN_SIOD 4
#define CAM_PIN_SIOC 5
#define CAM_PIN_D7 16
#define CAM_PIN_D6 17
#define CAM_PIN_D5 18
#define CAM_PIN_D4 12
#define CAM_PIN_D3 10
#define CAM_PIN_D2 8
#define CAM_PIN_D1 9
#define CAM_PIN_D0 11
#define CAM_PIN_VSYNC 6
#define CAM_PIN_HREF 7
#define CAM_PIN_PCLK 13

// ------------------------------ OLED (I2C) --------------------------------
// SSD1306 128x64. Its own I2C bus, separate from the camera's SCCB lines.
#define PIN_OLED_SDA 47
#define PIN_OLED_SCL 48
#define OLED_I2C_ADDR 0x3C
#define OLED_WIDTH 128
#define OLED_HEIGHT 64

// ----------------------- microphone: I2S RX (INMP441) ----------------------
// I2S peripheral 0. INMP441 L/R pin tied to GND => data on the left channel.
#define PIN_MIC_WS 38   // LRCL / word select
#define PIN_MIC_SCK 39  // BCLK
#define PIN_MIC_SD 40   // DOUT of mic -> DIN of ESP32

// ------------------- speaker: I2S TX (MAX98357A class-D) -------------------
// I2S peripheral 1. Leave the amp's GAIN pin floating for 9 dB.
#define PIN_SPK_BCLK 41
#define PIN_SPK_LRC 42
#define PIN_SPK_DIN 21

// --------------------------- servos & buttons ------------------------------
// FS90R / MG90S continuous-rotation servos drive the two tracks. A third
// standard (180 deg) servo pans the head. All driven by LEDC hardware PWM.
#define PIN_SERVO_LEFT 2
#define PIN_SERVO_RIGHT 3
#define PIN_SERVO_HEAD 14
#define PIN_BUTTON 0  // on-board BOOT button: push-to-talk / factory reset

// Continuous-rotation servos are centred at ~1500 us. Every servo is slightly
// off; trim these until the tracks are still when the robot is idle.
#define SERVO_LEFT_STOP_US 1500
#define SERVO_RIGHT_STOP_US 1500
// Full speed offset from stop. 200-400 us is the usable range on FS90R.
#define SERVO_SPAN_US 320
// The two servos face opposite directions, so one must be inverted.
#define SERVO_LEFT_INVERT 0
#define SERVO_RIGHT_INVERT 1
// Head pan limits in degrees, measured from the mechanical centre.
#define SERVO_HEAD_MIN_DEG 45
#define SERVO_HEAD_MAX_DEG 135
// Motion never runs longer than this without a fresh command (dead-man switch).
#define MOTOR_WATCHDOG_MS 1500

// ------------------------------- battery ----------------------------------
// 2S Li-ion (7.4 V nominal) through a divider into ADC1. With 100k/100k the
// ratio is 2.0; adjust if you use different resistors.
#define PIN_BATTERY_ADC 1
#define BATTERY_DIVIDER_RATIO 2.0f
#define BATTERY_LOW_MV 6600   // warn: ~3.3 V/cell
#define BATTERY_CRIT_MV 6200  // stop moving: ~3.1 V/cell
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

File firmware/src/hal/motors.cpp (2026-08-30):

// SPDX-License-Identifier: MIT
#include "motors.h"

#include "config.h"

#if WALLE_ENABLE_MOTORS

#include <Arduino.h>
#include <ESP32Servo.h>

namespace {

Servo gLeft, gRight, gHead;
bool gReady = false;
bool gInhibited = false;

MoveCmd gCmd = MOVE_STOP;
uint8_t gSpeed = 0;
uint32_t gStopAt = 0;   // millis deadline, 0 while stopped
int16_t gHeadDeg = (SERVO_HEAD_MIN_DEG + SERVO_HEAD_MAX_DEG) / 2;

uint32_t gWiggleNext = 0;
uint8_t gWigglePhase = 0;

// Converts a signed -100..100 throttle into a servo pulse width. Continuous
// rotation servos read pulse width as *speed*, not position: STOP_US means
// stationary and the sign of the offset picks the direction.
int leftPulse(int throttle) {
  if (SERVO_LEFT_INVERT) throttle = -throttle;
  return SERVO_LEFT_STOP_US + (throttle * SERVO_SPAN_US) / 100;
}
int rightPulse(int throttle) {
  if (SERVO_RIGHT_INVERT) throttle = -throttle;
  return SERVO_RIGHT_STOP_US + (throttle * SERVO_SPAN_US) / 100;
}

void drive(int leftThrottle, int rightThrottle) {
  if (!gReady) return;
  gLeft.writeMicroseconds(leftPulse(leftThrottle));
  gRight.writeMicroseconds(rightPulse(rightThrottle));
}

}  // namespace

namespace motors {

bool begin() {
  // ESP32Servo needs explicit LEDC timer allocation on the S3.
  ESP32PWM::allocateTimer(0);
  ESP32PWM::allocateTimer(1);
  ESP32PWM::allocateTimer(2);
  gLeft.setPeriodHertz(50);
  gRight.setPeriodHertz(50);
  gHead.setPeriodHertz(50);
  gLeft.attach(PIN_SERVO_LEFT, 500, 2500);
  gRight.attach(PIN_SERVO_RIGHT, 500, 2500);
  gHead.attach(PIN_SERVO_HEAD, 500, 2500);
  gReady = true;
  drive(0, 0);
  gHead.write(gHeadDeg);
  return true;
}

void move(MoveCmd cmd, uint8_t speed, uint32_t durationMs) {
  if (!gReady) return;
  if (gInhibited && cmd != MOVE_STOP) return;
  if (speed > 100) speed = 100;

  gCmd = cmd;
  gSpeed = speed;

  // Every motion is time-boxed. Explicit duration wins, otherwise the
  // dead-man watchdog applies.
  uint32_t limit = durationMs ? durationMs : MOTOR_WATCHDOG_MS;
  if (limit > MOTOR_WATCHDOG_MS && cmd != MOVE_WIGGLE) limit = MOTOR_WATCHDOG_MS;
  gStopAt = (cmd == MOVE_STOP) ? 0 : millis() + limit;

  switch (cmd) {
    case MOVE_FORWARD: drive(speed, speed); break;
    case MOVE_BACK:    drive(-(int)speed, -(int)speed); break;
    case MOVE_LEFT:    drive(-(int)speed, speed); break;
    case MOVE_RIGHT:   drive(speed, -(int)speed); break;
    case MOVE_WIGGLE:
      gWigglePhase = 0;
      gWiggleNext = millis();
      break;
    case MOVE_STOP:
    default:
      drive(0, 0);
      gCmd = MOVE_STOP;
      break;
  }
}

void stop() {
  gCmd = MOVE_STOP;
  gStopAt = 0;
  drive(0, 0);
}

void setHead(int16_t degrees) {
  if (!gReady) return;
  if (degrees < SERVO_HEAD_MIN_DEG) degrees = SERVO_HEAD_MIN_DEG;
  if (degrees > SERVO_HEAD_MAX_DEG) degrees = SERVO_HEAD_MAX_DEG;
  gHeadDeg = degrees;
  gHead.write(gHeadDeg);
}

int16_t headAngle() { return gHeadDeg; }

bool isMoving() { return gCmd != MOVE_STOP; }

void setInhibited(bool inhibited) {
  gInhibited = inhibited;
  if (inhibited) stop();
}

void tick() {
  if (!gReady || gCmd == MOVE_STOP) return;
  const uint32_t now = millis();

  if (gCmd == MOVE_WIGGLE && now >= gWiggleNext) {
    // Alternate spin directions six times, ~120 ms each.
    if (gWigglePhase >= 6) {
      stop();
      return;
    }
    const int t = (gWigglePhase % 2) ? gSpeed : -(int)gSpeed;
    drive(t, -t);
    gWigglePhase++;
    gWiggleNext = now + 120;
    return;
  }

  if (gStopAt && now >= gStopAt) stop();
}

MoveCmd cmdFromName(const char *name) {
  if (!name) return MOVE_STOP;
  if (!strcmp(name, "forward")) return MOVE_FORWARD;
  if (!strcmp(name, "back") || !strcmp(name, "backward")) return MOVE_BACK;
  if (!strcmp(name, "left")) return MOVE_LEFT;
  if (!strcmp(name, "right")) return MOVE_RIGHT;
  if (!strcmp(name, "wiggle") || !strcmp(name, "dance")) return MOVE_WIGGLE;
  return MOVE_STOP;
}

}  // namespace motors

#else  // !WALLE_ENABLE_MOTORS

namespace motors {
bool begin() { return true; }
void move(MoveCmd, uint8_t, uint32_t) {}
void stop() {}
void setHead(int16_t) {}
int16_t headAngle() { return 90; }
void tick() {}
bool isMoving() { return false; }
void setInhibited(bool) {}
MoveCmd cmdFromName(const char *) { return MOVE_STOP; }
}  // namespace motors

#endif

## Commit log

2026-08-30 Add ESP32 Wall-E firmware and off-device AI server
    Firmware (firmware/, ESP32-S3 + Arduino via PlatformIO):
    - Layered HAL: I2S mic capture with rolling pre-roll, I2S speaker with a
    PSRAM jitter buffer, OV2640 stills, animated SSD1306 faces, track/head
    servos with a dead-man watchdog, battery sensing with a motion cutout.
    - Offline wake word via ESP-SR WakeNet fed from our own I2S path, with a
    push-to-talk fallback so the build never depends on it.
    - Single WebSocket link carrying JSON control frames and binary audio/JPEG,
    plus ArduinoOTA and server-triggered pull updates.
    - The microphone paces the main loop at 50 Hz, so the state machine runs
    without a single delay() call.
    Server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
    [partitions.csv]
2026-08-30 Add printable chassis, documentation and CI
    3D models (3d-models/):
    - Parametric OpenSCAD sources for all 11 parts, driven by one shared
    parameter file, plus a Makefile to render them.
    - A stdlib-only solid modeller (tools/meshlib.py) so the repo ships real
    STLs without requiring OpenSCAD. Parts are built as unions of watertight
    primitives with holes extruded into the geometry rather than subtracted;
    polygons with holes are triangulated by ear clipping after each hole is
    bridged in along a verified-clear segment.
    - Every part is validated for watertightness and bed size before it is
    written, and again in tests, so a modelling error fails at generation
    time instead of four hours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
    [arm.stl, battery_tray.stl, bom.csv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]
2026-08-30 Close out every turn explicitly instead of on a timeout
    End-to-end testing against the real server surfaced two bugs.
    The device leaves THINKING when speech starts arriving, but a turn that
    produces no speech - nothing intelligible was heard, or an engine failed -
    sent only face updates. The robot then sat in THINKING until its 20 second
    backstop timeout, unable to wake, after every misheard utterance. Added a
    `turn_end` control message that the server sends at the end of every turn,
    including the skipped ones, and which the firmware acts on. Barge-in
    deliberately does not send it: a new turn has already started and the device
    is listening. The simulator finished in 0.12 s afterwards, again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
    [main.cpp, test_session.py]
2026-08-30 Fix firmware build: drop the unresolvable esp32-camera dependency
    CI's PlatformIO job failed at dependency resolution:
    Library Manager: Installing espressif/esp32-camera @ ^2.0.15
    UnknownPackageError: Could not find the package with
    'espressif/esp32-camera @ ^2.0.15' requirements
    No such package exists in the PlatformIO registry, and the entry was
    unnecessary: Arduino-ESP32 core 3.x bundles the OV2640 driver in its
    precompiled ESP-IDF libraries. Verified against the downloaded framework
    rather than assumed - esp32s3/flags/includes carries
    espressif__esp32-camera/driver/include and ld_libs carries
    -lespressif__esp32-camera, so esp_camera.h resolves and links with no
    dependency a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
    [audio_in.cpp, display.cpp]
2026-08-30 Fix six defects found in review
    All six checked against the code before acting; every one reproduced.
    Firmware:
    - audio_out's no-PSRAM fallback allocated half a second of samples while
    every ring operation kept wrapping at the four-second kRingSamples. Past
    8000 samples it wrote straight off the end of the allocation. The actual
    allocated capacity is now tracked and used everywhere, and the smaller
    buffer is announced on the serial log.
    - The WALLE_ENABLE_* flags were defined unconditionally, so they overrode
    the -D flags from the walle-minimal environment. The documented bring-up
    build still compiled in the camera and motors it promises to omit -
    which is worse than a norma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
    [audio_out.cpp, config.h, main.cpp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]
2026-08-30 Make protocol.h self-contained, and compile it in CI
    The firmware build got past dependency resolution and into the compiler,
    where it failed on the first translation unit that includes protocol.h
    without Arduino.h ahead of it:
    src/core/protocol.h:103: error: 'size_t' has not been declared
    The header used size_t while including only <stdint.h>. Every other file
    happened to include Arduino.h first and got it transitively; vad.cpp did
    not. Added <stddef.h> - a header has to stand on its own.
    Rather than fix that blind and wait another CI cycle to find the next one,
    protocol.h is now compiled and executed as part of the test suite.
    firmware/test/test_protocol_host.cpp includes it first,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
